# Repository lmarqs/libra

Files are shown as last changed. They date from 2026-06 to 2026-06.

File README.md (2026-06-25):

# Libra

<p align="center">
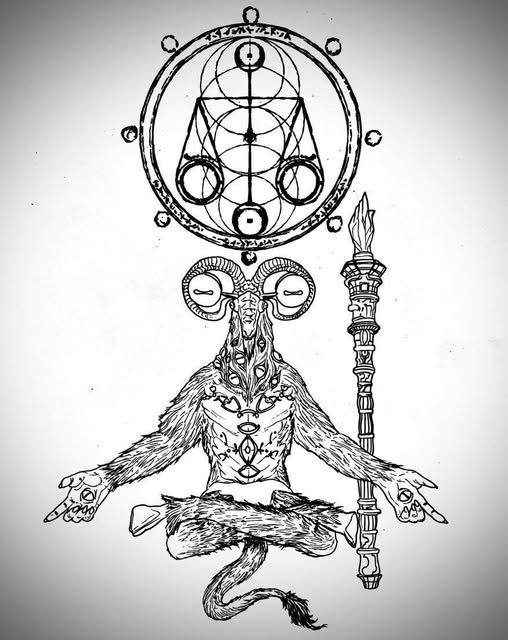
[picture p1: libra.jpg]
Libra emblem — a balanced, cross-legged figure beneath a scale-like sigil
  
</p>

A self-balancing **beam** for hands-on PID experimentation.

A weighing-scale–style beam pivots at its center, with a brushless motor +
propeller at each end. Differential propeller thrust rotates the beam; an
MPU6050 measures the beam's tilt; a PID loop running on an **ESP32** (C3 Super
Mini or WROOM-32) drives the two ESCs to hold a target angle (level by default). It's a
single rotational axis — the simplest interesting plant for learning to tune P,
I, and D. Tuning and telemetry are over the USB serial console, or over an optional
WiFi web UI (target tilt, PID gains, arm/disarm). It boots disarmed; the ESC power
supply also has a separate hardware switch.

## Hardware

| Part | Notes |
|---|---|
| ESP32-C3 Super Mini *or* ESP32 WROOM-32 | Controller. C3 = single-core RISC-V + native USB; WROOM-32 = dual-core + USB-UART bridge. |
| MPU6050 | 6-axis IMU, I2C. Mounted on the beam to read tilt. |
| 2× brushless motor + ESC | 1000–2000 µs ESCs, driven at 200 Hz / sub-µs via LEDC. Arming is a hardware power switch. |
| 2× propeller | One per beam end, providing the balancing thrust. |
| LiPo battery | Powers the motors through the ESCs (behind the hardware arm switch). |

Pins are board-specific — literal `-D` flags per `[env]` in `platformio.ini`
(`src/config.h` defaults apply when unset). Verify against your board's silkscreen.
**C3 Super Mini:** I2C `SDA=GPIO2`, `SCL=GPIO3`; ESCs on `GPIO0`/`GPIO1` (`GPIO2` is
a strapping pin but fine for SDA — I2C idles high; keep `GPIO8`/`GPIO9` and USB
`GPIO18`/`GPIO19` free). **WROOM-32:** I2C `SDA=GPIO32`, `SCL=GPIO33`; ESCs on
`GPIO16` (left/m1) / `GPIO17` (right/m2) — non-strapping and free on the plain
WROOM-32 (the WROVER variant reuses 16/17 for PSRAM); avoid the classic-ESP32
strapping pins `GPIO0`/`GPIO2`/`GPIO12`/`GPIO15`.

**Reference build** (what this is validated on): 1404 4600 KV motors, Afro Mini
ESCs (SimonK/BLHeli), Gemfan 3523-3 props, 3S LiPo, and a hardware switch on the
ESC power as the arm. Any standard 1000–2000 µs ESC + small brushless motor works —
expect to re-find the usable throttle band for your motor (see
[docs/testing.md](docs/testing.md) → Bench testing & ESC calibration).

### Printed frame

The mechanical rig is 3D-printed — sources and print files live in
[`docs/3dprint/`](docs/3dprint/). The base and tower raise the pivot; the arm
pivots on the tower with a motor plate bolted to each end:

| Part | Role |
|---|---|
| [`base`](docs/3dprint/base.png) | Wide honeycombed foot that sits on the desk; the square center socket holds the tower. |
| [`tower`](docs/3dprint/tower.png) | Vertical post that plugs into the base and raises the pivot off the bench. |
| [`arm`](docs/3dprint/arm.png) | The balancing beam: a central pivot hub (rides on the tower) with a motor plate at each end. |
| [`plate`](docs/3dprint/plate.png) | Motor mount — one bolts to each end of the arm and carries a brushless motor (the 4-hole bolt pattern). |

Each part ships in four formats: `.f3d` (Fusion 360 source — edit here), `.stl` and
`.3mf` (print-ready mesh for your slicer), and `.png` (a render preview).

### Flashing

The C3 Super Mini has native USB — just plug it in and run `mise run upload`. If
the upload can't connect, enter download mode once: hold **BOOT**, tap **RST**,
release BOOT, then upload (the USB-CDC auto-reset handles it after that).

> ⚠️ **Props spin.** Bench-test with propellers removed or the beam clamped.
> Boots **disarmed** — arm from the web UI when ready, and the ESC supply also has a
> separate **hardware switch** (keep it OFF until you trust your gains). The tilt
> failsafe cuts the motors and latches disarmed.

## Architecture

A dedicated, core-pinned control task reads the IMU, runs the control policy, and
drives the ESCs, sleeping to its period (`xTaskDelayUntil`) between steps and polling
the USB serial console non-blockingly so it never stalls. It's pinned to the APP core
(core 1 on the dual-core WROOM-32 — isolated from the WiFi stack on core 0; the only
core on the C3) at a priority above the web server but below WiFi, so control stays
responsive while WiFi is never starved. The optional web UI runs as an HTTP server
(ESP-IDF `httpd`) in its own task; it exchanges the setpoint, gains, telemetry, and
arm/disarm (the software master-enable) with the control task — the ESC supply is a
separate hardware switch. `dt` is measured each step, so it tolerates timing jitter.

```mermaid
flowchart LR
    mpu["MPU6050 IMU"] -->|I2C| loop
    subgraph c3["ESP32 (C3 single-core / WROOM-32 dual-core)"]
        direction TB
        loop["control loop @200 Hz<br/>Imu → Balancer.step() → EscPair"]
        serial["USB serial console<br/>tuning + telemetry"]
        web["httpd :80 (own task)<br/>/ · /telemetry · /set"]
        serial <-->|"kp/ki/kd · sp · ?"| loop
        web <-->|"sp · kp/ki/kd · arm · telemetry"| loop
    end
    loop -->|"1000–2000 µs PWM"| esc["2× ESC → motor → prop"]
    browser["Browser<br/>arm + tilt + gain sliders"] <-->|"WiFi AP · HTTP"| web
```

The control policy lives in `Balancer.step()` (`lib/balancer/`): fuse the tilt
estimate, trip the failsafe past the limit, otherwise run PID into the mixer.
While disarmed or tripped the motors idle; the integrator resets on each (re-)arm so
stale wind-up can't kick.

```mermaid
flowchart LR
    accel["accel angle"] --> filt["ComplementaryFilter"]
    rate["gyro rate"] --> filt
    filt -->|"fused tilt"| trip{"abs(angle) ><br/>tilt limit?"}
    trip -->|yes| idle["idle motors<br/>+ trip failsafe"]
    trip -->|"no"| pid["Pid<br/>(anti-windup)"]
    sp["setpoint"] --> pid
    pid -->|correction| mix["Mixer<br/>(base ± correction)"]
    mix --> out["m1, m2 → ESCs"]
```

**Host/hardware split.** `lib/{filter,pid,mixer,balancer}` are pure C++ with no
Arduino deps, so the whole control policy is unit-tested on the host
(`mise run test`). `Imu` and `EscPair` are Arduino-only hardware drivers.

## PID control

Balancing the beam is the whole point — a single rotational axis is the simplest
interesting plant for learning to tune a **PID** controller by hand. Each step the
loop measures the tilt, computes one corrective number, and turns it into
differential propeller thrust; the beam moves, the IMU re-measures, and the cycle
repeats 200×/s (`Balancer::step` → `Pid::update` → `Mixer::mix`).

```mermaid
flowchart LR
    sp["setpoint<br/>(target tilt)"] --> e{{"error<br/>= setpoint − angle"}}
    imu["measured tilt<br/>(fused IMU angle)"] --> e
    e --> p["P = Kp · error<br/>correct now"]
    e --> i["I = Ki · Σ(error·dt)<br/>cancel a steady lean"]
    imu --> d["D = −Kd · Δangle/dt<br/>damp the swing"]
    p --> sum(("Σ"))
    i --> sum
    d --> sum
    sum -->|"correction (clamped ±kPidOutLimit)"| mix["Mixer<br/>m1 = base + correction<br/>m2 = base − correction"]
    mix -->|differential thrust| beam["beam rotates"]
    beam -.->|IMU re-measures| imu
```

The controller sums three responses to the **error** (how far the tilt is from the
target). The mixer turns that single correction into two throttles around a common
`base` — one motor speeds up while the other slows down — which is what rotates the
beam.

| Term | Gain (cmd) | What it contributes | Default |
|---|---|---|---|
| **P** — proportional | `kp` | A restoring push proportional to the current error (throttle fraction per degree of tilt) — the main spring. *Too high → oscillation.* | `0.002` |
| **I** — integral | `ki` | Sums past error to cancel a constant offset P alone can't hold (e.g. an off-center load). *Too high → slow overshoot / hunting.* | `0.000` (off) |
| **D** — derivative | `kd` | Reacts to how fast the tilt is changing and brakes it before it overshoots. Taken on the *measurement*, not the error, so moving the setpoint doesn't kick the motors. *Too high → jitter on sensor noise.* | `0.0008` |

Bounds keep it safe: each motor command is clamped to the throttle band
`[kMinThrottle, kMaxThrottle]` around the hover point `kBaseThrottle` (the PID's authority is
sized so a full correction can drive one motor to `kMaxThrottle` while the other drops to
`kMinThrottle`), and past `kTiltLimitDeg` the tilt failsafe cuts both motors and latches
disarmed (see the ⚠️ safety notes above).

### Tuning

Tune **live** — set gains with `kp`/`ki`/`kd <v>` and nudge the target with
`sp <deg>`, over serial or the web sliders (command reference in *Tuning over
serial* below). Keep **props off or the beam clamped** until the gains are sane.

1. Start with `ki 0` and `kd 0`; raise `kp` until the beam fights back toward level
   but slightly oscillates.
2. Add `kd` to damp that oscillation — increase until the swing settles cleanly
   without buzzing on noise.
3. Add a little `ki` *only* if the beam holds a constant offset from level; back it
   off if it starts a slow hunting overshoot.

Watch the response with `mise run probe` (one `?` state line: `angle`, `out`,
`m1`/`m2`, gains) or `mise run stream` (continuous).

### Testing

`lib/pid` (with `filter`/`mixer`/`balancer`) is pure, host-tested math — run the
unit cases with no hardware, then tune the gains on the rig:

```sh
mise run test     # Unity cases for pid / filter / mixer / balancer
```

## Toolchain

Everything runs through [mise](https://mise.jdx.dev/), which loads `.env` and
manages the Python venv holding PlatformIO. **Always use the mise tasks** so the
environment is set up correctly.

```sh
mise run setup     # one-time: create .env + venv, install PlatformIO
mise run build     # compile the default env (esp32-wroom32)
mise run upload    # build + flash over USB
mise run monitor   # open the serial monitor (115200 baud)
mise run run       # build + upload + monitor
mise run test      # host-side unit tests (pid / filter / mixer / balancer)
mise run format    # clang-format src/ lib/ test/
mise run probe     # ask the board its state over serial ('?')
mise run banner    # reset + capture the boot banner
mise run stream    # capture serial output (e.g. the debug IMU stream)
```

**Testing & debugging** — host tests, flashing, talking to the board, the debug
log level, and IMU bring-up are covered in **[docs/testing.md](docs/testing.md)**.

## Configuration

Deployment tunables come from **`.env`** (gitignored — `mise run setup` copies
`.env.example`); mise loads `.env` and PlatformIO injects each as a `-D` build flag,
with `src/config.h` defaults applying when unset. The board **pin map** is separate:
literal `-D` flags per `[env]` in `platformio.ini`, not `.env`. **Edit `.env` (or the
env's pins), then rebuild** (`mise run build` / `upload`) to apply.

| Variable | Default | Purpose |
|---|---|---|
| `LIBRA_THROTTLE_MIN` | `0.0` | Hard floor of the per-motor throttle band (0..1 fraction of the ESC's 1000–2000 µs range) — a motor never goes below it. |
| `LIBRA_THROTTLE_MID` | `0.0` | Hover point — where both motors rest at zero error. Set independently within `[MIN, MAX]`. |
| `LIBRA_THROTTLE_MAX` | `0.0` | Hard ceiling — a motor never goes beyond it. PID authority is derived to reach the farther edge from `MID`, so the motors sweep `[MIN, MAX]`. Ships as a zero band (inert) — set all three to your motor before balancing does anything. |
| `LIBRA_TILT_LIMIT_DEG` | `45.0` | Tilt failsafe — past this many degrees the motors cut and latch disabled. |
| `LIBRA_ANGLE_OFFSET_DEG` | `0.0` | Tilt zero-offset (deg), subtracted so a physically level beam reads 0. |
| `LIBRA_AP_SSID` | `libra` | WiFi SoftAP name for the web UI. |
| `LIBRA_AP_PASS` | `thebalancebot` | WPA2 password for that AP (web UI can arm, so it's secured by default — a public default, override it in `.env`). Empty or `< 8` chars → open AP. |

(Pin map is not here — it's board-specific `-D` flags in `platformio.ini`; see [Hardware](#hardware).)

**Convention:** name new **tunables** `LIBRA_<AREA>_<NAME>`, document them in
`.env.example` with their default, and back each with an `#ifndef` default in
`src/config.h`. Board pins are literal `-D` flags in `platformio.ini` per `[env]`,
not `.env` knobs (see [CLAUDE.md](CLAUDE.md) for the full pattern).

## Tuning over serial

Open the serial monitor (`mise run monitor`, 115200 baud) and type commands:

| Command | Effect |
|---|---|
| `kp <v>` / `ki <v>` / `kd <v>` | set a PID gain live |
| `sp <v>` | set the target tilt, degrees |
| `?` | print state (angle, output, motor throttles, gains) |

There is no *serial* arm/disarm — **arm/disarm is from the web UI** (the software
master-enable; boots disarmed), and the **ESC supply has a separate hardware switch**.
Exceeding the tilt limit cuts the motors and latches disarmed (re-arm from the web).
The setpoint and gains (`sp`, `kp`, `ki`, `kd`) are also settable from the web UI below.

## Web control

On boot the board starts a WiFi access point and a small web UI for live tuning:

1. Join the WiFi network named by `LIBRA_AP_SSID` (default `libra`). It ships
   **WPA2-secured** with the default password `thebalancebot` (`LIBRA_AP_PASS`);
   change it in `.env`, or set it empty for an open AP.
2. Browse to **`http://192.168.4.1/`**.
3. **ARM** / **DISARM** with the buttons, and use the sliders for target tilt + PID
   gains. The page shows the live angle and the armed/tripped state.

The web UI sets the setpoint, gains, and **arm/disarm** (the software master-enable);
it cannot change a limit, and a web-set target is clamped to the tilt limit. The board
boots **disarmed**, and the ESC power is behind a separate hardware switch — but since
the web can arm, the AP is **WPA2-secured by default** (`LIBRA_AP_PASS=thebalancebot`).
That default is public, so **change `LIBRA_AP_PASS`** when props are on or anyone could be
in range — and never set it empty (open AP, any client can arm) in an untrusted RF area.

## Status

Built incrementally:

- **M0** — toolchain + docs: builds, flashes, prints a boot banner.
- **M1** — IMU angle readout (complementary filter).
- **M2** — ESC bring-up + arming.
- **M3** — closed PID loop with tilt failsafe + serial tuning.
- **M4** — WiFi web UI: live tuning + two-layer arming (boots disarmed; ESC power on a separate hardware switch).
- **M5** — props-off bench tooling: per-motor manual drive + ESC throttle-range calibration & sweep.

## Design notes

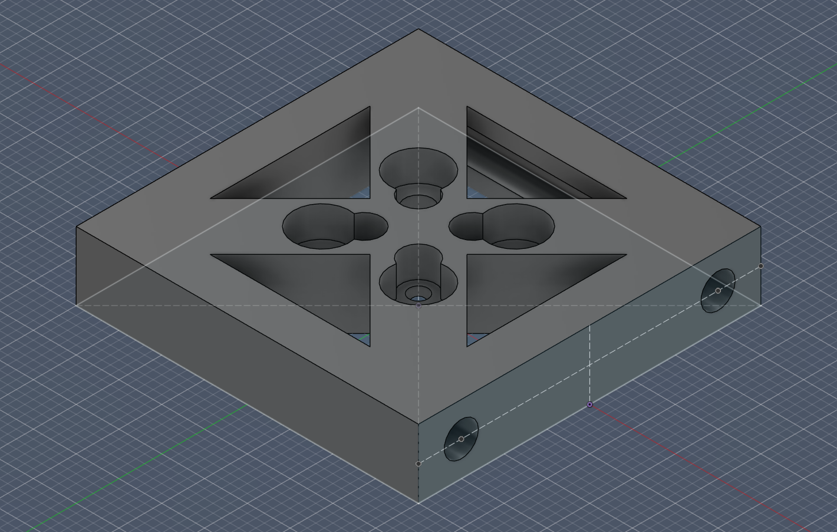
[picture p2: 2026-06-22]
docs/3dprint/plate.png

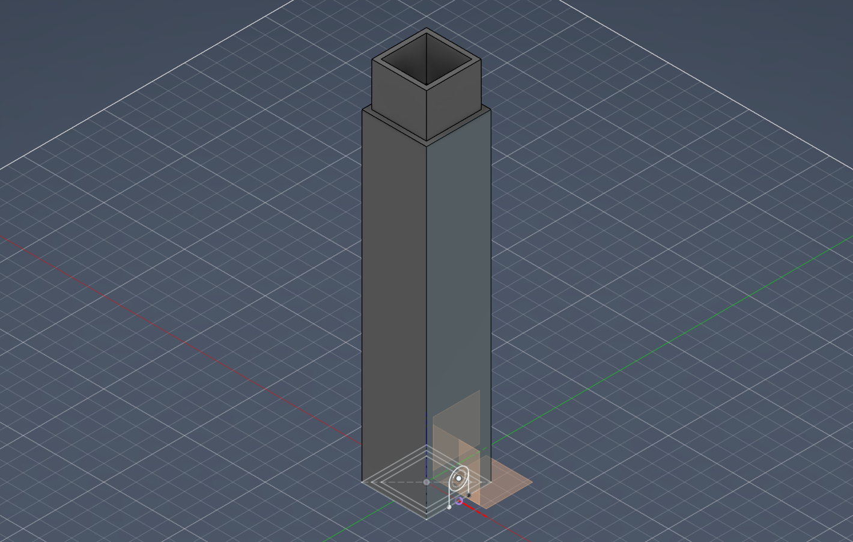
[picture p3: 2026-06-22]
docs/3dprint/tower.png

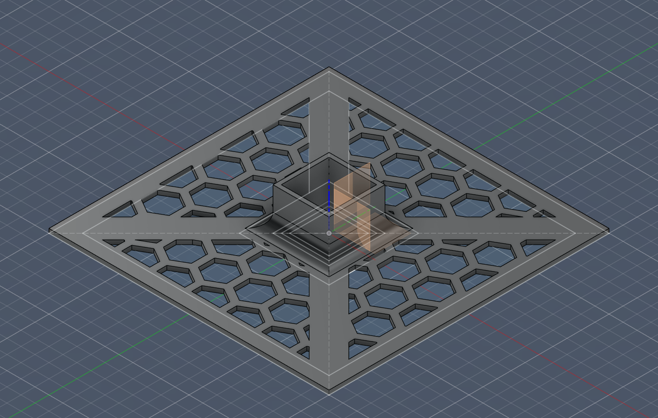
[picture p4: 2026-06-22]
docs/3dprint/base.png

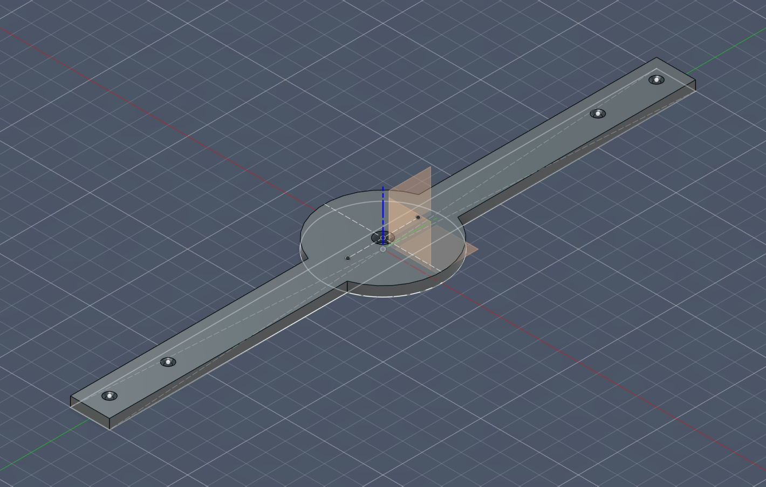
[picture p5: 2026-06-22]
docs/3dprint/arm.png

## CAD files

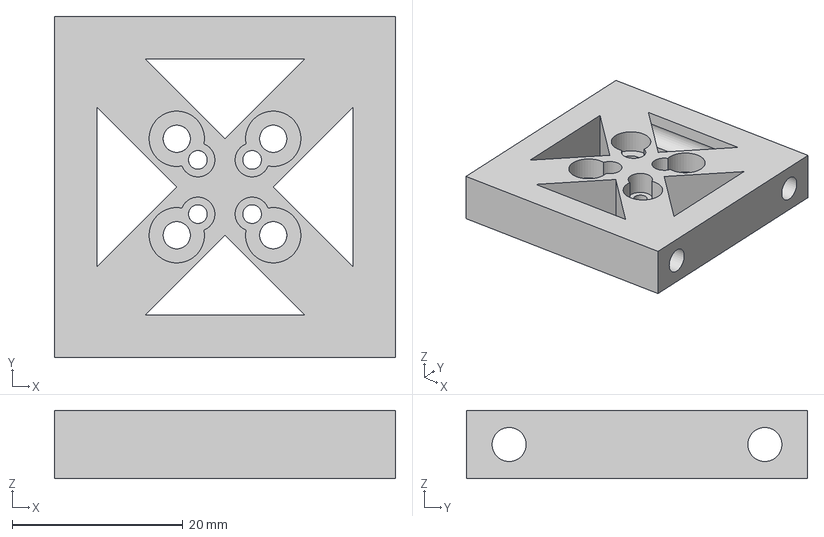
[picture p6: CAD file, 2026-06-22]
docs/3dprint/plate.3mf
40.0 x 40.0 x 8.00 mm

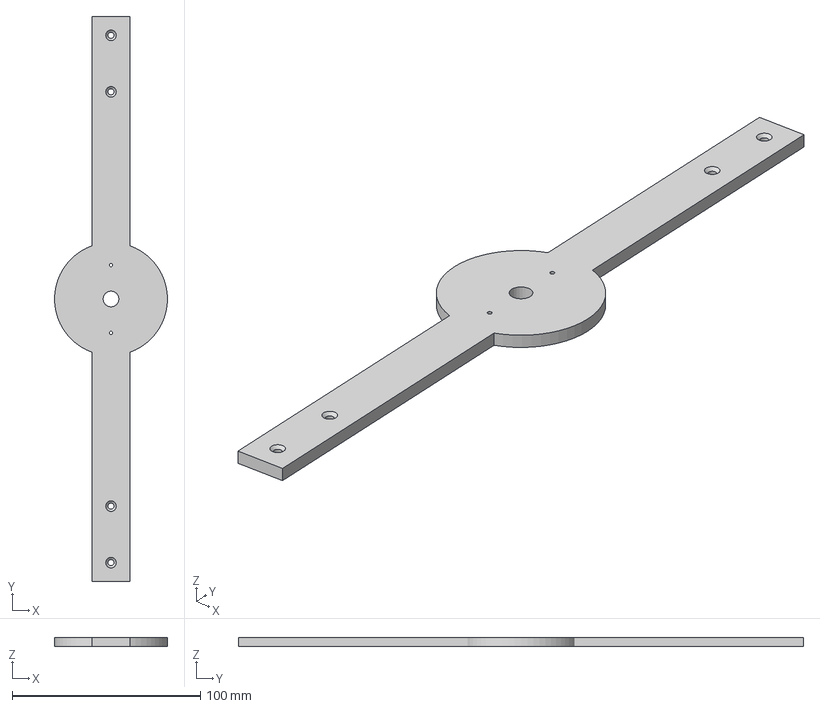
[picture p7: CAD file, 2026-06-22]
docs/3dprint/arm.3mf
60.0 x 300.0 x 5.00 mm

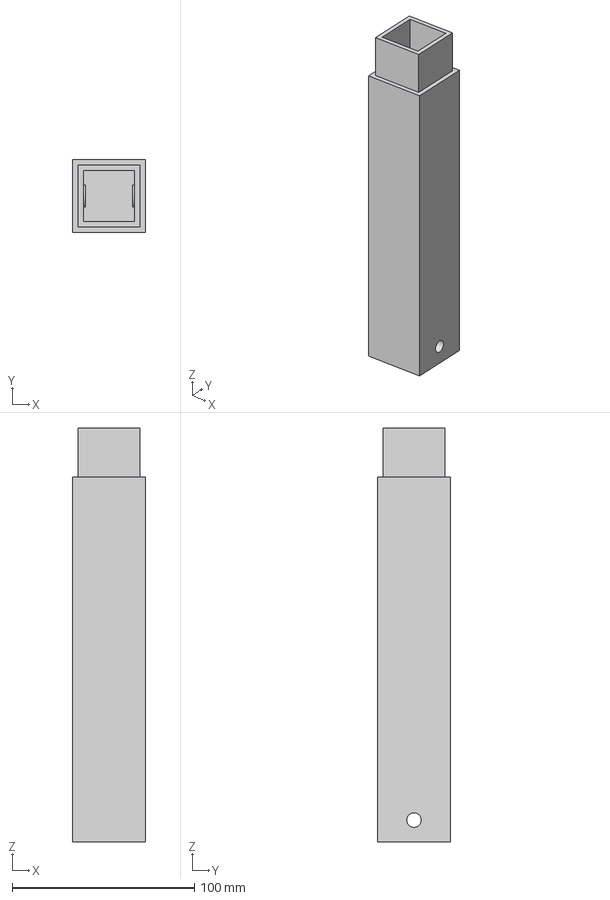
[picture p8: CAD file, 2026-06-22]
docs/3dprint/tower.3mf
40.0 x 40.0 x 227.0 mm

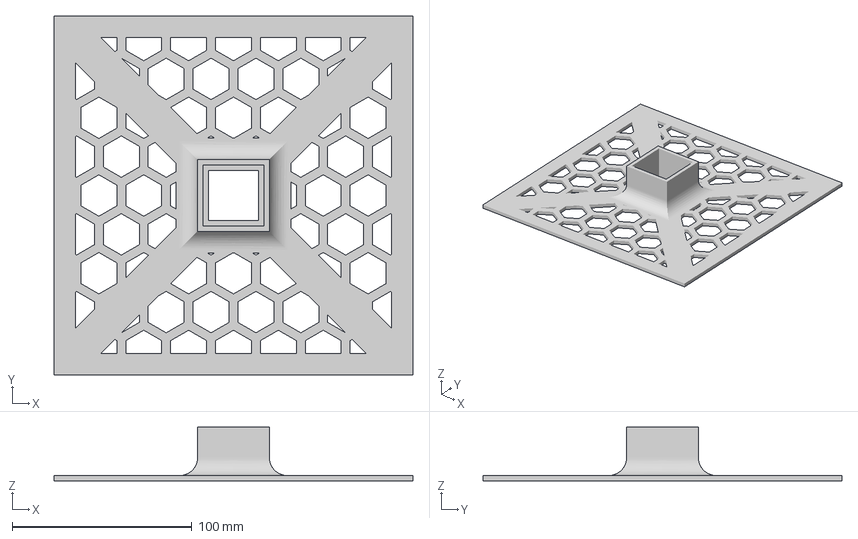
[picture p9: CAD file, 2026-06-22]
docs/3dprint/base.3mf
200.0 x 200.0 x 30.0 mm

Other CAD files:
docs/3dprint/arm.f3d
docs/3dprint/arm.stl
docs/3dprint/base.f3d
docs/3dprint/base.stl
docs/3dprint/plate.f3d
docs/3dprint/plate.stl
docs/3dprint/tower.f3d
docs/3dprint/tower.stl

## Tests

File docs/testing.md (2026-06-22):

# Testing & debugging

How to test and debug Libra effectively — host tests, build/flash, talking to the
board, debug logging, and sensor bring-up. The fast loop is host unit tests; the
board is reached over serial, non-interactively.

## TL;DR — the loop

```sh
mise run test          # host unit tests (pure libs) — fast, no hardware
mise run build         # compile the default env (esp32-wroom32)
mise run build:all     # compile BOTH boards — the dual-arch gate
mise run upload        # flash over USB
mise run probe         # ask the board its state ('?') and print the reply
mise run banner        # reset + capture the boot banner
mise run stream        # capture serial for 30s (e.g. the debug IMU stream)
mise run format-check  # clang-format clean
```

Gate before declaring a change done: **`mise run test` + `mise run format-check` + `mise run build:all`**.

## 1. Host unit tests — the primary correctness loop

The pure control libs (`lib/{pid,filter,mixer,balancer}`) have **no Arduino deps**
and are unit-tested on the host via the PlatformIO `native` env:

```sh
mise run test          # Unity tests; currently 21 cases
```

This needs no board and runs in seconds — do most logic work here. **Add or extend
Unity tests in `test/` whenever you touch a pure lib.** Hardware drivers (`imu`,
`esc`, `web`) are deliberately *not* host-compiled, so keep Arduino/`Wire`/WiFi
includes out of the pure libs (the `native` env would fail to build them).

## 2. Build & flash

Two boards build from one tree (per-board pin map + flags live in `platformio.ini`):
the **ESP32-C3 Super Mini** (single-core, native USB) and the **ESP32 WROOM-32**
(dual-core, USB-UART bridge). `mise run build` compiles the default env
(`esp32-wroom32`); target a specific board by passing the env through mise:

```sh
mise run build                            # default env (esp32-wroom32)
mise run build:all                        # both boards — dual-arch compile gate
mise x -- pio run -e esp32-c3-super-mini  # just the C3
mise run upload                           # build + flash (default env)
mise run run                              # build + upload + monitor, in order
```

If `upload` can't connect on the C3, enter download mode once: hold **BOOT**, tap
**RST**, release BOOT, then upload. USB-CDC auto-reset handles it afterwards.

### Concurrency / core model (both archs)

The control loop runs in a dedicated `controlTask` pinned to `ARDUINO_RUNNING_CORE`:
the **APP core (1)** on the dual-core WROOM-32 (isolated from WiFi/`httpd` on the PRO
core 0), and the **only core (0)** on the single-core C3 (where its priority `10` —
above `httpd`, below lwIP/WiFi — plus the per-period `xTaskDelayUntil` yield keep WiFi
alive). A `LIBRA_LOG_LEVEL>=4` build logs the task's core and stack high-water-mark, so
you can confirm `core=1` on the WROOM / `core=0` on the C3 and that the 8 KB stack has
headroom. See CLAUDE.md → Gotchas for the full rationale and the watchdog invariant.

## 3. Talking to the board over serial

### Why the monitor looks dead

The firmware prints a boot banner **once** and then only replies to commands — it
does not stream by default. And the C3's native USB-CDC does **not** reset the chip
when a monitor attaches (unlike a UART bridge), so the banner has already scrolled
past. Result: `mise run monitor` shows a blank screen until you type. That's
expected, not a fault. Type `?` for a state line, or press **RST** to re-emit the
banner.

### Non-interactive helpers (preferred)

`tools/serial_dbg.py` (wrapped by mise) talks to the board without a live terminal —
scriptable, CI/agent-friendly, and it resets the board cleanly (pulses EN via RTS
into the **app**, not the bootloader):

```sh
mise run probe                                           # send '?', print the state line
mise x -- python tools/serial_dbg.py probe --cmd "kp 0.02"   # send any command
mise run banner                                          # reset + capture the boot banner
mise run stream                                          # capture 30s of serial
mise x -- python tools/serial_dbg.py stream --seconds 20 --grep "gx="  # filter lines
```

A typical `probe` reply (all serial output now goes through the ESP32 `log_*` API, so each
line carries a `[time][level][file:line] func():` prefix — the `state:` fields follow it):

```
[ 12345][I][main.cpp:127] handleCommand(): state: angle=-0.24 sp=0.00 out=0.000 m1=0.00 m2=0.00 kp=0.0100 ki=0.0000 kd=0.0008
```

The state line is `log_i`, so `probe`/`banner` need `LIBRA_LOG_LEVEL >= 3` (the default) to
see it; below 3 only errors/warnings print.

### Serial command reference

| Command | Effect |
|---|---|
| `kp <v>` / `ki <v>` / `kd <v>` | set a PID gain live |
| `sp <v>` | set the target tilt, degrees |
| `?` | print state (angle, output, throttles, gains; or bench throttle) |
| `set motors_enabled on\|off` | bench: drive the motors at the set speeds, or hold both idle — props off |
| `set motors_speed <m1> <m2>` | bench: per-motor throttle, each 0..1 (full range, for calibration) |
| `run` | leave bench and resume balancing |
| `x` | stop: hold motors idle (the hardware ESC switch is the real kill) |

The four bench rows (`set motors_*`, `run`, `x`) exist only in a **`LIBRA_BENCH_ENABLED=1`**
build (§7); otherwise just `kp/ki/kd/sp/?`. Setpoint, gains, **and arm/disarm** are settable from
the WiFi web UI (the software master-enable; boots disarmed) — the ESC supply is a separate
hardware switch (see §7).

## 4. Debug logging — env-var log level

**All** serial output goes through the ESP32 `log_*` API (`CORE_DEBUG_LEVEL`), driven by
`LIBRA_LOG_LEVEL` in `.env` (0=none, 1=error, 2=warn, 3=info, 4=debug, 5=verbose). So the
level gates everything, not just the IMU stream — each line is prefixed
`[time][level][file:line] func():`:

- **≥ 1 (error)** failures: `MPU6050 not found`, `WiFi SoftAP failed`, `HTTP server failed`.
- **≥ 2 (warn)** invalid-command help.
- **≥ 3 (info)** the boot banner, `state:` replies, and AP join/leave events. This is why
  `probe`/`banner` need level ≥ 3 (the default). Bench/calibration prompts are `log_w` (≥ 2).
- **≥ 4 (debug)** compiles in a ~10 Hz raw-IMU stream via `log_d()` — the bring-up tool.
  Below 4 it is compiled out entirely (zero runtime cost).
- `Serial.setDebugOutput(true)` routes `log_*()` to the USB-CDC — load-bearing for *all*
  output now, not just debug.
- Default is **3**; bump to 4, rebuild, and watch with `mise run stream` only while
  bringing up the IMU.

```sh
# enable the IMU stream
sed -i 's/^LIBRA_LOG_LEVEL=.*/LIBRA_LOG_LEVEL=4/' .env && mise run upload
mise run stream                       # lines look like: ... step(): ax=.. gx=.. acc=.. fused=..
```

Each line carries the raw accel (`ax/ay/az`, g), gyro (`gx/gy/gz`, °/s), the
accel-derived angle (`acc`), and the filtered angle (`fused`).

## 5. Sensor bring-up — IMU axis & zero-offset

The IMU mapping is mounting-specific. To (re-)derive it after a remount:

1. Build with `LIBRA_LOG_LEVEL=4`, flash, and `mise run stream`.
2. Move the beam: **hold level → rotate CW and hold → level → rotate CCW → level**,
   pausing between phases.
3. Read off the trace:
   - **Accel angle axis** — at level, see which accel axis carries ~+1 g. Gravity
     resting on +X with tilt swinging into Y means the angle is `atan2(ay, ax)`
     (set in `Imu::accelAngleDeg`).
   - **Pivot gyro axis + sign** — the gyro axis that spikes during rotation is the
     rate. Use it negated/un-negated so the **fused** angle tracks **acc** during
     motion (here `-s.gz`, in `main.cpp`). If fused lags or diverges from acc, flip
     the sign.
   - **Zero-offset** — read the steady angle at physical level and put it in
     `LIBRA_ANGLE_OFFSET_DEG` (`.env`) so level reads 0.

This rig's result: `atan2(ay, ax)`, rate `-s.gz`, offset `-3.4°`.

## 6. WSL2 serial notes

- Device: **`/dev/ttyACM0`** — the C3's built-in USB-Serial/JTAG (VID:PID
  `303A:1001`), shared into WSL via `usbipd-win`.
- **Port busy** (`Could not exclusively lock port … Resource temporarily
  unavailable`): a monitor holds it. Close `mise run monitor`/`run`, or find the
  holder: `lsof /dev/ttyACM0`, `fuser -v /dev/ttyACM0`, or scan
  `/proc/*/fd` for the symlink to `ttyACM0`.
- A reset re-enumerates USB; `usbipd` can detach the device — re-attach from
  Windows (`usbipd attach --wsl --busid <id>`) if `/dev/ttyACM0` disappears.

## 7. Bench testing & ESC calibration (props off)

**Arming is two-layer.** The board boots **disarmed**; you arm/disarm the software master-enable
from the web UI, and the **ESC power supply has a separate hardware switch** (keep it OFF until
ready). The tilt failsafe cuts the motors and latches disarmed around `LIBRA_TILT_LIMIT_DEG`.
Always bench-test with **props off or the beam clamped**.

The bench commands are **compiled out by default** — build with `LIBRA_BENCH_ENABLED=1` in
`.env` to use them, and set it back to `0` for a props-on build. They drive the ESCs directly
and **bypass both the `kMaxThrottle` cap and the tilt failsafe** (you raise throttle yourself;
nothing auto-jumps), which is why they are gated and props-off only. The serial commands are
`set motors_enabled on|off`, `set motors_speed <m1> <m2>` (each 0..1), `run` (resume balancing),
`x` (idle) — see §3.

### Find the usable band — `mise run sweep`

`tools/sweep.py` ramps the throttle and holds each step so you can watch the motor and read the
pulse it sends. It reports throttle as a *fraction* of the firmware's real **200 Hz /
1000–2000 µs** signal (driven sub-µs off LEDC, ~0.3 µs steps) — not the duty cycle of a bench
PWM generator, which the ESC reads differently (4 kHz @ 39/79% ≈ 98/198 µs, far below the 1–2 ms
the ESC expects).

```sh
mise run sweep                                                # 0.00->0.10, both motors
mise x -- python tools/sweep.py 0.07 0.10 0.001 2             # narrow + fine, 2 s holds
mise x -- python tools/sweep.py 0.07 0.10 0.001 2 --motor seq # test each motor in turn
mise x -- python tools/sweep.py --port /dev/ttyACM0          # C3 port
```

`--motor 1|2|seq` drives one motor at a time — handy when only one spins (an armed ESC that
ignores throttle on one channel points at *that* ESC's power/arming or a wiring/pin issue, not
the firmware). Note the **spin-start** (lowest throttle that turns the prop) and a usable top
speed. *(Reference build — 1404 4600 KV on 3S, Gemfan 3523-3, Afro Mini — spins from ~1080 µs
and is plenty by ~1090 µs.)*

### Set the operating band

The balancer drives both motors within a throttle band set in `.env` by three knobs — 0..1
fractions of the ESC's 1000–2000 µs range:

- `LIBRA_THROTTLE_MIN` — hard floor; a motor never goes below it (keep it at or above the
  spin-start so both motors stay turning).
- `LIBRA_THROTTLE_MID` — the hover point; where both motors rest at zero error.
- `LIBRA_THROTTLE_MAX` — hard ceiling; a motor never goes beyond it.

`kBaseThrottle` is `MID`; `kPidOutLimit` in `config.h` is *derived* as the max headroom
(`max(MAX − MID, MID − MIN)`), so a full correction can drive a motor to the farther edge and the
mixer clamp holds the nearer one — a motor sweeps the whole `[MIN, MAX]`. The committed default is
a **zero band `[0.0, 0.0]`** with hover 0, so a fresh build is inert until you set a real band.
Widening the band raises both thrust and control authority — a change the safety rules guard (see
[CLAUDE.md](../CLAUDE.md)).

### Optional: ESC throttle-range calibration (SimonK / BLHeli)

Only needed if the ESC's learned range is off (the motor refuses to spin until very high
throttle). The ESC must see **MAX at power-up**, and `escs.begin()` holds MIN for ~3 s at boot,
so the ESC must be on a **switch separate from the board** — you present MAX yourself:

1. ESC switch **OFF**; boot the board (it emits its arm signal at MIN, then idles).
2. `set motors_speed 1 1` then `set motors_enabled on` — firmware now streams MAX.
3. Switch the ESC **ON**: it powers up seeing MAX and beeps to record the top.
4. `set motors_speed 0 0` — drops to MIN; the ESC beeps to store the range.
5. `run`, then switch the ESC **OFF**. Re-sweep to confirm the spin-start dropped near idle.

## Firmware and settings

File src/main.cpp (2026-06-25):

// Libra — self-balancing beam (ESP32-C3 single-core and ESP32 WROOM-32 dual-core).
//
// A dedicated fixed-rate control task reads the IMU, runs the control policy
// (complementary filter -> PID -> mixer), and drives the two ESCs — gated by a software
// master-enable (armed from the web UI; boots DISARMED) and the tilt failsafe. The ESC
// supply is gated by a separate HARDWARE switch. Tuning + telemetry are over USB serial
// and the WiFi web UI (setpoint, gains, arm/disarm).
//
// Concurrency model (see CLAUDE.md): the control task is pinned to
// ARDUINO_RUNNING_CORE — the APP core (1) on the dual-core WROOM, isolated from the
// WiFi/lwIP/httpd stack on the PRO core (0); the only core on the single-core C3,
// where priority + a per-period yield keep WiFi alive instead.
//
//   ⚠️  Boots DISARMED. Arm/disarm from the web UI (the software master-enable); the ESC
//       supply is a separate HARDWARE switch — keep it OFF until ready. Past the tilt limit
//       the failsafe cuts the motors and latches DISARMED — re-arm from the web. Props off
//       / beam clamped while you trust your gains.
//
// Serial commands (USB-CDC, 115200): kp <v> | ki <v> | kd <v> | sp <v> | ?
//   Bench / ESC calibration (PROPS OFF): set motors_enabled on|off | set motors_speed <m1> <m2> | run | x
//   (motors default to 0 and only move when enabled; raise to 1.0 then 0.0 by hand to calibrate.)
//
// Build with LIBRA_LOG_LEVEL>=4 (.env -> CORE_DEBUG_LEVEL) to stream raw IMU
// readings over serial via log_d() — used for IMU axis/bias bring-up.

#include <Arduino.h>
#include <Balancer.h>
#include <EscPair.h>
#include <Imu.h>
#include <Throttle.h>
#include <Wire.h>

#include "config.h"
#include "web.h"

static Imu imu(config::kMpuAddress);
static EscPair escs(config::kEsc1Pin, config::kEsc2Pin);
static Balancer balancer(ComplementaryFilter(config::kFilterAlpha),
                         Pid({config::kKp, config::kKi, config::kKd}, -config::kPidOutLimit, config::kPidOutLimit),
                         Mixer(config::kBaseThrottle, config::kMinThrottle, config::kMaxThrottle),
                         config::kTiltLimitDeg);

// Operator + control state — single execution context (controlTask), so plain variables.
static Pid::Gains gains{config::kKp, config::kKi, config::kKd};
static float setpoint = config::kSetpointDeg;
static bool enabled = false;  // software master-enable; boots DISARMED, armed from the web UI
static ControlOutputs last{};

// Bench / manual-drive override (controlTask-owned), compiled in only with LIBRA_BENCH_ENABLED.
// While `benchActive`, the control loop skips balancing and the operator drives each ESC
// directly: `motorsOn` gates whether the per-motor speeds are applied or both held at idle
// (min). Speeds default to 0, so nothing ever jumps to throttle on its own — for ESC
// calibration you raise them to 1.0 yourself. Props-off bench only; it bypasses the
// kMaxThrottle cap and the tilt failsafe, which is why it is gated off by default.
#if LIBRA_BENCH_ENABLED
static bool benchActive = false;              // manual mode engaged (balancing suspended)
static bool motorsOn = false;                 // drive the speeds, vs. hold both at idle
static float m1Speed = 0.0f, m2Speed = 0.0f;  // per-motor bench throttle, 0..1
#endif

// --- Control task placement (timers/tasks/loops; dual-arch) ---
#ifndef ARDUINO_RUNNING_CORE
#define ARDUINO_RUNNING_CORE 0  // defensive; the framework defines it (1 on dual, 0 on C3)
#endif
// Run control on ARDUINO_RUNNING_CORE: the APP core (1) on the dual-core WROOM —
// physically isolated from WiFi/lwIP/httpd on the PRO core (0) — and the only core on
// the single-core C3, where the priority below + the per-period yield keep WiFi alive.
static constexpr BaseType_t kControlCore = ARDUINO_RUNNING_CORE;
// Above httpd (tskIDLE_PRIORITY+5 = 5) so control preempts the web server on the C3;
// below lwIP (18) / WiFi (23) so the WiFi stack is never starved. MUST stay < 18.
static constexpr UBaseType_t kControlPrio = 10;
// Matches the Arduino loopTask budget; the step path uses String/snprintf/atan2f.
static constexpr uint32_t kControlStackBytes = 8192;

static void step(float dt) {
#if LIBRA_BENCH_ENABLED
  // Bench override: drive each ESC at its manual speed (or hold idle) and skip balancing.
  // Still publish (with bench=true) so the web UI never shows a safe-looking state while
  // the motors are live.
  if (benchActive) {
    escs.writeThrottle(motorsOn ? m1Speed : 0.0f, motorsOn ? m2Speed : 0.0f);
    web::publish(last.angle, enabled, /*tripped=*/false, /*bench=*/true, gains, setpoint);
    return;
  }
#endif

  web::poll(gains, setpoint);  // apply any web-set gains/setpoint before computing
  const int arm = web::pollArm();
  if (arm >= 0) enabled = (arm == 1);  // web arm/disarm; control loop owns `enabled`

  ImuSample s;
  if (!imu.read(s)) return;
  // The beam pivots about the IMU's Z axis; -s.gz is its rate (negated to match
  // the sign of the accel-derived angle, verified during bring-up). Flip if the
  // gyro fights the accelerometer instead of complementing it.
  balancer.setGains(gains);
  const float angle = Imu::accelAngleDeg(s) - config::kAngleOffsetDeg;  // zero-trim to level
  const ControlInputs in{angle, -s.gz, setpoint, dt, enabled};
  last = balancer.step(in);

  if (last.active) {
    escs.writeThrottle(last.m1, last.m2);
  } else {
    escs.disarm();
  }
  if (last.tripped) enabled = false;  // tilt failsafe latches DISARMED — re-arm from the web

  // Raw-IMU bring-up stream — compiled in only at debug verbosity
  // (LIBRA_LOG_LEVEL >= 4). Throttled to ~10 Hz at the 200 Hz loop.
#if CORE_DEBUG_LEVEL >= 4
  {
    static uint8_t n = 0;
    if (++n >= 20) {
      n = 0;
      log_d("ax=%+.3f ay=%+.3f az=%+.3f | gx=%+.2f gy=%+.2f gz=%+.2f | acc=%+.1f fused=%+.1f", s.ax, s.ay, s.az, s.gx,
            s.gy, s.gz, angle, last.angle);
      // Confirm the control task's stack budget is comfortable during bring-up.
      log_d("control: core=%d stack_free=%u words", xPortGetCoreID(), uxTaskGetStackHighWaterMark(nullptr));
    }
  }
#endif

  web::publish(last.angle, enabled, last.tripped, /*bench=*/false, gains, setpoint);
}

static void handleCommand(String line) {
  line.trim();
  if (line.length() == 0) return;
  if (line == "?") {
#if LIBRA_BENCH_ENABLED
    if (benchActive) {
      log_i("state: BENCH motors=%s m1=%.3f m2=%.3f sp=%.2f kp=%.4f ki=%.4f kd=%.4f", motorsOn ? "ON" : "off", m1Speed,
            m2Speed, setpoint, gains.kp, gains.ki, gains.kd);
    } else
#endif
    {
      log_i("state: %s%s angle=%.2f sp=%.2f out=%.3f m1=%.2f m2=%.2f kp=%.4f ki=%.4f kd=%.4f",
            enabled ? "ARMED" : "disarmed", last.tripped ? " TRIPPED" : "", last.angle, setpoint, last.output, last.m1,
            last.m2, gains.kp, gains.ki, gains.kd);
    }
  }
#if LIBRA_BENCH_ENABLED
  else if (line.startsWith("set motors_enabled ")) {
    // Master switch for manual bench drive. ON applies the per-motor speeds (which default to
    // 0, so enabling never spins on its own); OFF / x holds both at idle. Both suspend
    // balancing — 'run' hands control back to the balancer.
    String v = line.substring(19);
    v.trim();
    v.toLowerCase();
    if (v == "on" || v == "1" || v == "true") {
      benchActive = true;
      motorsOn = true;
      log_w("motors ENABLED (PROPS OFF!) — m1=%.3f m2=%.3f", m1Speed, m2Speed);
      if (m1Speed > config::kMaxThrottle || m2Speed > config::kMaxThrottle) {
        log_w("  note: above the balancing cap kMaxThrottle=%.3f (calibration level).", config::kMaxThrottle);
      }
    } else if (v == "off" || v == "0" || v == "false") {
      benchActive = true;
      motorsOn = false;
      log_i("motors OFF (idle). 'run' resumes balancing.");
    } else {
      log_w("usage: set motors_enabled on|off");
    }
  } else if (line.startsWith("set motors_speed ")) {
    // Per-motor bench throttle: set motors_speed <m1> <m2>, each 0..1. Stored at once and
    // applied while enabled; full range so you can teach the ESC max/min (1.0 then 0.0) by hand.
    String rest = line.substring(17);
    rest.trim();
    const int gap = rest.indexOf(' ');
    if (gap < 0) {
      log_w("usage: set motors_speed <m1> <m2>  (each 0..1)");
    } else {
      m1Speed = throttle::clamp01(rest.substring(0, gap).toFloat());
      m2Speed = throttle::clamp01(rest.substring(gap + 1).toFloat());
      const float u1 = escs.minUs() + m1Speed * (escs.maxUs() - escs.minUs());
      const float u2 = escs.minUs() + m2Speed * (escs.maxUs() - escs.minUs());
      log_i("motors_speed m1=%.4f (%.2f us) m2=%.4f (%.2f us)%s", m1Speed, u1, m2Speed, u2,
            motorsOn ? "" : " — enable with 'set motors_enabled on'");
    }
  } else if (line == "run") {
    benchActive = false;
    log_i("bench off — balancing");
  } else if (line == "x") {
    // Emergency idle (alias for 'set motors_enabled off'): hold both at min. The hardware ESC
    // switch is the real kill; this just parks the signal until 'run'.
    benchActive = true;
    motorsOn = false;
    log_w("STOP: motors idle. 'run' resumes balancing.");
  }
#endif
  else if (line.startsWith("kp ")) {
    gains.kp = line.substring(3).toFloat();
  } else if (line.startsWith("ki ")) {
    gains.ki = line.substring(3).toFloat();
  } else if (line.startsWith("kd ")) {
    gains.kd = line.substring(3).toFloat();
  } else if (line.startsWith("sp ")) {
    setpoint = line.substring(3).toFloat();
  } else {
#if LIBRA_BENCH_ENABLED
    log_w(
        "commands: kp<v> ki<v> kd<v> sp<v> ? | bench(PROPS OFF): set motors_enabled on|off | set motors_speed <m1> "
        "<m2> | run | x");
#else
    log_w("commands: kp<v> ki<v> kd<v> sp<v> ?");
#endif
  }
}

static void pollSerial() {
  static String line;
  while (Serial.available()) {
    const char c = static_cast<char>(Serial.read());
    if (c == '\n' || c == '\r') {
      handleCommand(line);
      line = "";
    } else {
      line += c;
    }
  }
}

// The fixed-rate control loop, in its own task (see the concurrency note at the top).
static void controlTask(void*) {
  TickType_t next_wake = xTaskGetTickCount();
  uint32_t last_us = micros();
  log_i("control task on core %d (prio %u)", xPortGetCoreID(), uxTaskPriorityGet(nullptr));
  for (;;) {
    // Sleep until the next control period — yields the core to WiFi/idle housekeeping
    // instead of busy-spinning. This yield is load-bearing: dropping it starves the
    // FreeRTOS idle task (the C3's shared core, or the WROOM's dedicated core-1 idle),
    // tripping the task watchdog. On an overrun xTaskDelayUntil returns pdFALSE without
    // sleeping, so yield explicitly to keep idle fed.
    if (xTaskDelayUntil(&next_wake, pdMS_TO_TICKS(1000UL / config::kLoopHz)) == pdFALSE) {
      taskYIELD();
    }

    pollSerial();  // polled once per period (200 Hz) — ample for typed commands

    const uint32_t now = micros();
    const float dt = (now - last_us) * 1e-6f;
    last_us = now;
    step(dt);
  }
}

void setup() {
  Serial.begin(115200);
  delay(200);
  Serial.setDebugOutput(true);  // route log_*() output to the USB-CDC serial
  log_i("boot — DISARMED. Arm from the web UI; the ESC supply has its own hardware switch.");

  Wire.begin(config::kI2cSda, config::kI2cScl);
  Wire.setClock(400000);
  // Bound a glitched/contended bus: a stalled read fails fast so step() just skips a
  // cycle instead of hanging the (now higher-priority) control task — which on the
  // WROOM would starve the core-1 idle task and trip its watchdog.
  Wire.setTimeOut(10);  // ms
  if (imu.begin()) {
    log_i("MPU6050 ready");
  } else {
    log_e("MPU6050 not found");
  }

  log_i("ESC arm signal (min throttle held ~3 s)...");
  escs.begin();  // blocks ~3 s arming; must complete before controlTask drives the ESCs
  log_i("ESCs ready (idle). DISARMED — arm from the web UI to balance.");

  web::begin();  // WiFi SoftAP + web UI (setpoint/gains + arm/disarm; WPA2 by default)

  // Hand the loop off to a dedicated, core-pinned task and reclaim loopTask's stack.
  // Created last: the IMU, ESCs, and WiFi are all up before control starts driving.
  xTaskCreatePinnedToCore(controlTask, "control", kControlStackBytes, nullptr, kControlPrio, nullptr, kControlCore);
  vTaskDelete(nullptr);  // setup() runs in loopTask; controlTask now owns the control loop
}

// Never runs after setup() deletes loopTask, but Arduino requires the symbol.
void loop() {}

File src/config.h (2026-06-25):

#pragma once

#include <cstdint>

// Central place for board-specific constants. Pins are for the ESP32-C3 Super
// Mini. VERIFY against your board's silkscreen before wiring. GPIO2 is a
// strapping pin used here for I2C SDA — fine because the bus idles high (the
// level GPIO2 wants at reset), but keep the other strapping pins (GPIO8/GPIO9)
// and the native-USB pins (GPIO18/GPIO19) free.
namespace config {

// --- I2C (MPU6050) ---
#ifndef LIBRA_I2C_SDA
#define LIBRA_I2C_SDA 2
#endif
#ifndef LIBRA_I2C_SCL
#define LIBRA_I2C_SCL 3
#endif
constexpr int kI2cSda = LIBRA_I2C_SDA;
constexpr int kI2cScl = LIBRA_I2C_SCL;
constexpr uint8_t kMpuAddress = 0x68;  // AD0 low

// --- ESC signal pins ---
#ifndef LIBRA_ESC_PIN1
#define LIBRA_ESC_PIN1 0
#endif
#ifndef LIBRA_ESC_PIN2
#define LIBRA_ESC_PIN2 1
#endif
constexpr int kEsc1Pin = LIBRA_ESC_PIN1;
constexpr int kEsc2Pin = LIBRA_ESC_PIN2;

// --- Tilt geometry ---
// The beam pivots about the IMU's Z axis: at rest gravity rests on +X, and
// rotating about Z swings it into Y, so gravity in the X/Y plane gives the tilt
// and the Z gyro axis (negated) gives its rate. Flip this if bring-up shows the
// angle responding to the wrong tilt or with the wrong sign (mounting-dependent).
// (Used by main.cpp when it maps an ImuSample to (accel_angle, rate).)
//
// Zero-offset (deg) subtracted from the measured tilt so a physically level beam
// reads 0. Mounting-specific — measure the resting angle and set it in .env.
// Defaults to 0 (no trim).
#ifndef LIBRA_ANGLE_OFFSET_DEG
#define LIBRA_ANGLE_OFFSET_DEG 0.0f
#endif
constexpr float kAngleOffsetDeg = LIBRA_ANGLE_OFFSET_DEG;

// --- Complementary filter ---
// Gyro weight; the remaining (1 - alpha) trusts the accelerometer.
constexpr float kFilterAlpha = 0.98f;

// --- Control loop ---
constexpr uint32_t kLoopHz = 200;
// The control task paces itself with xTaskDelayUntil at the FreeRTOS tick (1 ms on
// arduino-esp32, configTICK_RATE_HZ == 1000, on both archs). The period is
// pdMS_TO_TICKS(1000 / kLoopHz); if kLoopHz doesn't divide 1000 the rate is silently
// quantized to whole ticks. Keep it an even divisor so 200 Hz stays exactly 200 Hz.
static_assert(1000UL % kLoopHz == 0, "kLoopHz must evenly divide 1000 (1 ms FreeRTOS tick)");

// --- PID (starting gains — tune live over serial) ---
constexpr float kKp = 0.002f;  // throttle fraction per degree of error (full correction ~2.5 deg)
constexpr float kKi = 0.000f;
constexpr float kKd = 0.0008f;

// --- Mixing, throttle band & setpoint (safety) ---
constexpr float kSetpointDeg = 0.0f;  // target tilt: level

// The balancer keeps both propellers inside a throttle band — the single source of motor
// commands (per-motor fraction, 0..1), enforced at the mixer. Three knobs set it:
//   - kMinThrottle (LIBRA_THROTTLE_MIN) — hard floor; a motor never goes below this,
//   - kBaseThrottle (LIBRA_THROTTLE_MID) — hover; where both motors rest at zero error,
//   - kMaxThrottle (LIBRA_THROTTLE_MAX) — hard ceiling; a motor never goes beyond this.
// The PID authority is DERIVED so a full correction can reach the farther band edge from the
// hover point; the mixer clamp holds the nearer edge. So the reachable per-motor range is the
// whole [kMinThrottle, kMaxThrottle] and nothing outside it, regardless of gains.
//
// Set from .env via LIBRA_THROTTLE_MIN / MID / MAX (mise injects them; see platformio.ini).
// Defaults to a ZERO band [0.0, 0.0] with hover 0 -> authority 0: a fresh build never drives
// the motors until you set a real band for your motor. Safe-by-default — the firmware ships
// inert. Fractions map onto the ESC's ~1000-2000 us range (0.0 -> 1000 us idle, 1.0 -> 2000 us
// full); the reference 1404 4600KV/3S rig balances around hover ~0.085 in [0.080, 0.090]
// (~1080-1090 us). Widening the band raises both thrust and control authority — a change the
// safety rules guard (see CLAUDE.md). Props off / beam clamped while you tune.
#ifndef LIBRA_THROTTLE_MIN
#define LIBRA_THROTTLE_MIN 0.0f
#endif
#ifndef LIBRA_THROTTLE_MID
#define LIBRA_THROTTLE_MID 0.0f
#endif
#ifndef LIBRA_THROTTLE_MAX
#define LIBRA_THROTTLE_MAX 0.0f
#endif
constexpr float kMinThrottle = LIBRA_THROTTLE_MIN;
constexpr float kMaxThrottle = LIBRA_THROTTLE_MAX;
constexpr float kBaseThrottle = LIBRA_THROTTLE_MID;  // hover point — set independently within the band
static_assert(kMinThrottle >= 0.0f, "LIBRA_THROTTLE_MIN must be >= 0");
static_assert(kMaxThrottle <= 1.0f, "LIBRA_THROTTLE_MAX must be <= 1 (full throttle)");
static_assert(kMinThrottle <= kMaxThrottle, "LIBRA_THROTTLE_MIN must not exceed LIBRA_THROTTLE_MAX");
static_assert(kBaseThrottle >= kMinThrottle && kBaseThrottle <= kMaxThrottle,
              "LIBRA_THROTTLE_MID (hover) must lie within [LIBRA_THROTTLE_MIN, LIBRA_THROTTLE_MAX]");
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

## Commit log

2026-06-20 chore: project tooling and build config
    PlatformIO + mise for the ESP32-CAM, with a host-only native env for unit
    tests. Fixes the copied-in scaffold (broken extends/default_envs, stale
    per-board tasks) and wires hexdump (asset embedding) into build.
2026-06-20 feat: pure control logic (pid, filter, mixer) with host tests
    Arduino-free, host-testable building blocks: a complementary filter for tilt
    estimation, a PID controller (derivative-on-measurement, output clamp,
    anti-windup), and the differential-thrust mixer. Covered by native Unity tests.
2026-06-20 feat: MPU6050 and ESC hardware drivers
    Imu reads raw accel/gyro over I2C with startup gyro-bias calibration; EscPair
    drives two 1000-2000us servo-PWM ESCs via ESP32Servo with an arming sequence.
    EscPair claims only LEDC timers 2 & 3, leaving timer 0 for the camera XCLK.
2026-06-20 feat: firmware app — control loop, camera, and web UI
    Core-1 control task (IMU -> filter -> PID -> mixer -> ESCs at 200 Hz) with tilt
    failsafe and master enable; core-0 WiFi AP plus two esp_http_server instances
    serving the camera MJPEG stream, telemetry JSON, and live gain tuning. The web
    page renders an FPV view with a telemetry OSD overlay and PID sliders. Cross-core
    state is spinlock-guarded in control_state.
    [config.h, main.cpp]
2026-06-20 docs: project README and contributor guide
    README covers the hardware, wiring/pins, flashing over FTDI, and the web UI.
    CLAUDE.md documents the toolchain, host/hardware split, and the LEDC timer
    constraint between the camera and the ESCs.
2026-06-20 refactor: extract host-tested Balancer for the control policy
    Composes the filter, PID, and mixer into one balancing policy and returns a
    ControlOutputs value. The failsafe-trip, idle-when-disabled, and
    integrator-reset-on-rearm logic now lives here (pure C++) instead of inline in
    the control task — and is covered by native tests for those safety behaviours.
    [test_balancer.cpp]
2026-06-20 refactor: route control loop through Balancer + harden web I/O
    Control task now reads the IMU, calls balancer.step(), and drives the ESCs from
    its ControlOutputs — the balancing policy no longer lives inline in main.
    control_state publishes the ControlOutputs value (no positional float clump) and
    exposes typed setKp/setKi/setKd instead of a stringly-typed setGain(char).
    telemetryHandler guards against an oversized snprintf length before sending,
    closing a latent out-of-bounds read.
    [main.cpp]
2026-06-20 style: leading underscore for private data members
    Switch the convention from trailing (member_) to leading (_member) across all
    the control classes (filter, pid, mixer, imu, esc, balancer). Mechanical rename;
    no behaviour change — tests and build are unaffected.
2026-06-20 docs: tighten CLAUDE.md and drop empty CONTEXT.md
    Promote safety to a top-level guardrail (props/motors are a physical-harm
    risk), make verification an explicit gate, fix stale default env
    (esp32-c3-super-mini -> esp32cam), add a leading-underscore convention
    note and a Gotchas section, and trim architecture narrative now covered
    by README. Remove the empty CONTEXT.md placeholder.
2026-06-20 feat: cap per-motor throttle via LIBRA_MAX_THROTTLE (.env), default 5%
    Enforce a hard ceiling on propeller output at the mixer (the single source
    of motor commands). The cap comes from the LIBRA_MAX_THROTTLE env var, which
    mise injects from .env into the esp32cam build flags; it defaults to 0.05
    (5%) when unset (src/config.h #ifndef + .env.example).
    Scale the operating envelope under the ceiling so the cap never starves
    control authority: base 0.03 +/- differential 0.02 keeps each motor in
    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
2026-06-20 feat: AP SSID/password from .env; rename throttle cap to LIBRA_THROTTLE_MAX
    Move the WiFi AP credentials to the same .env -> mise -> build-flag path as
    the throttle cap: LIBRA_AP_SSID / LIBRA_AP_PASSWORD, quote-wrapped in
    platformio.ini so they reach the compiler as string literals, with the
    prior values ("libra" / "balancebot") as src/config.h defaults.
    Also rename the throttle ceiling var LIBRA_MAX_THROTTLE -> LIBRA_THROTTLE_MAX
    for a consistent LIBRA_THROTTLE_* prefix.
2026-06-20 docs: document the .env -> build-flag config standard
    Add a Configuration section to README (variable table + edit/rebuild flow)
    and a Build-time config convention to CLAUDE.md (naming, quote-wrapping for
    strings, the #ifndef default pattern). Also fix two stale ESP32-C3
    references in the Toolchain block.
2026-06-20 docs: sync stale doc claims with code
    docu-optimizer sync pass found drift between the docs and the code:
    - mise.toml: build comment still named the ESP32-C3 + native USB-CDC;
    correct it to the AI-Thinker ESP32-CAM flashed over USB-TTL/FTDI.
    - main.cpp: document the 'x' emergency-stop serial alias (accepted but
    absent from the command list + usage string).
    - README: the test task also covers the balancer suite; drop the stale
    "(this commit)" marker from the M0 milestone.
    [main.cpp]
2026-06-20 feat: sharpen camera stream (jpeg quality 12->10, +contrast)
    Lower the JPEG quantization on the PSRAM (VGA) path for crisper frames and
    nudge contrast up one step (the OV2640 has no sharpness control). Note in
    the code that a soft image is most often the lens being out of focus.
2026-06-20 feat: capture at XGA + log PSRAM path to fix fullscreen blur
    The web UI shows the stream fullscreen, so a VGA (or QVGA-fallback) frame is
    upscaled by the browser and looks soft regardless of lens focus or sensor.
    Capture at XGA (1024x768) on the PSRAM path so there are enough real pixels
    to fill the display, and log whether PSRAM was detected so a silent QVGA
    fallback (the worst case) is obvious in the boot log.
2026-06-20 refactor: drop camera/WiFi/web — single-core ESP32-C3, serial-only
    Pivot back to the ESP32-C3 Super Mini and strip the FPV/web stack:
    - Board: esp32cam -> esp32-c3-devkitm-1 (env esp32-c3-super-mini); native
    USB-CDC for serial (ARDUINO_USB_MODE / CDC_ON_BOOT), no FTDI/PSRAM/assets.
    - Delete src/camera.*, src/web.*, src/control_state.*, and assets/. The C3 is
    single-core, so the dual-core split + spinlock-guarded shared state are gone:
    main.cpp is now one fixed-rate loop() that polls serial then steps control.
    - Tuning + telemetry move to the serial console (e/d/x/kp/ki/kd/sp/?).
    - config.h: C3 pin map (SDA=5, SCL=6, ESC 3/4), drop AP creds + control core.
    - EscPair: no camera conten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
    [config.h, main.cpp]
2026-06-21 feat: env-configurable pins + tilt limit; move I2C to 2/3, ESCs to 0/1
    Reassign the pin map (SDA=GPIO2, SCL=GPIO3, ESC1=GPIO0, ESC2=GPIO1) and make
    the pins and the tilt failsafe angle .env-tunable via build flags, same
    pattern as LIBRA_THROTTLE_MAX:
    LIBRA_I2C_SDA / LIBRA_I2C_SCL (default 2 / 3)
    LIBRA_ESC_PIN1 / LIBRA_ESC_PIN2 (default 0 / 1)
    LIBRA_TILT_LIMIT_DEG (default 45.0)
    Each has an #ifndef default in config.h so a flag-less build still works.
    GPIO2 (SDA) is a strapping pin — fine since I2C idles high; noted in config.h
    and README. Docs (.env.example, README config table + pins note) updated.
    [config.h]
2026-06-21 feat: env-configurable WiFi AP credentials
    Add LIBRA_AP_SSID / LIBRA_AP_PASSWORD knobs (defaults libra / balancebot)
    following the existing env→build-flag→config.h convention, for the
    upcoming tuning web UI. WPA2 needs an 8-63 char password.
2026-06-21 feat: web module — WiFi SoftAP + httpd tuning UI
    New Arduino-only src/web: a WPA2 SoftAP and an ESP-IDF httpd server on
    :80 serving a one-page UI (/, /telemetry, /set) with sliders for the
    setpoint and PID gains. httpd handlers run in their own task, so the
    small command/telemetry state is spinlock-guarded and exchanged with the
    control loop via web::poll() / web::publish().
    Safety by construction: /set carries setpoint + gains only (no arm), and
    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
2026-06-21 docs: document the web tuning UI
    README: serial+web framing, web path in Diagram 1, a Web control section,
    Configuration rows, and a tuning note. CLAUDE.md: safety bullet (web sets
    setpoint/gains only, never arm), src/web layout entry, and a replaced
    gotcha for the WiFi web UI.
2026-06-21 fix(imu): correct pivot axis to Z; add env-var debug logging
    Hardware bring-up showed the IMU rests with gravity on +X and pivots
    about Z, not X. accelAngleDeg now uses atan2(ay, ax) and the control
    loop uses -s.gz as the rate (was atan2(ay, az) / s.gx). Level now reads
    ~0deg instead of ~135deg, so the tilt failsafe no longer trips at rest.
    Verified on serial: steady at level, tracks +/-tilt smoothly, and the
    fused angle stays within ~1deg of the accel angle in motion (gyro
    complements rather than fights).
    Debug logging via the ESP32 API: LIBRA_LOG_LEVEL (.env) -> CORE_DEBUG_LEVEL.
    At >=4 (debug) it compiles in a ~10 Hz raw-IMU serial stream (log_d) used
    for this bring-up, plus the AP passw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
    [config.h, main.cpp]
2026-06-21 feat: env-configurable IMU tilt zero-offset (LIBRA_ANGLE_OFFSET_DEG)
    Subtract a configurable zero-offset from the measured tilt so a
    physically level beam reads 0deg. Default 0.0 (no trim); set in .env
    after measuring the resting angle with LIBRA_LOG_LEVEL=4. On this rig
    -3.4 zeroes it (verified: level now reads ~0.2deg, was -3.4deg).
    Follows the established .env -> build-flag -> config.h #ifndef ->
    constexpr convention; applied in main.cpp's ImuSample -> ControlInputs
    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
2026-06-21 docs: document the test/debug strategy + add serial-debug tooling
    Capture the bring-up workflow this hardware needs so it is repeatable:
    - tools/serial_dbg.py: non-interactive serial helper (probe/banner/stream).
    The firmware only prints on boot + on command and native USB-CDC does not
    reset on monitor attach, so an interactive monitor looks dead. These talk
    to the board headlessly and reset it cleanly (RTS pulse into the app).
    - mise tasks: probe / banner / stream wrap it for one-command use.
    - docs/testing.md: full guide — host tests (the fast loop), build/flash,
    the monitor-looks-dead gotcha, LIBRA_LOG_LEVEL debug stream, IMU axis +
    zero-offset bring-up, WSL2 serial/port-busy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
    [serial_dbg.py]
2026-06-21 fix(loop): yield the core to WiFi via vTaskDelayUntil
    The single-core C3 ran loop() as a tight busy-wait between 5 ms control steps,
    starving the FreeRTOS idle task and WiFi/lwIP housekeeping. Sleep to the next
    period instead so the radio gets the core; dt stays measured from micros().
    [main.cpp]
2026-06-21 feat(web): open AP, /set lock-scope fix, client join/leave logging
    - Parse /set query args before taking the spinlock — no string/float parsing
    with interrupts disabled on the WiFi core.
    - SoftAP is now open (no WPA2); arming stays serial-only so no thrust is exposed,
    and it avoids WPA2 association failures. Drops the unused kApPassword.
    - Log AP client join/leave events unconditionally, for connection debugging.
    [config.h]
2026-06-21 build: per-board pin map + ESP32 WROOM-32 env
    Pins are board hardware, so they live as literal -D flags per [env] (not .env).
    Shared tunables move to a [tunables] section interpolated into each board via
    ${tunables.build_flags}; .env still overrides them. Adds the esp32-wroom32 env
    (USB-UART bridge, I2C SDA=32/SCL=33, ESC 25/26 — all non-strapping pins).
2026-06-21 refactor: drop unused kLoopPeriodUs
    The loop computes its period from kLoopHz via pdMS_TO_TICKS(); kLoopPeriodUs is
    no longer referenced after the vTaskDelayUntil change.
    [config.h]
2026-06-21 docs(readme): open AP, per-board pins, WROOM-32 board
    Sync the README with this session's changes: SoftAP is open (drop the WPA2
    password references), the pin map moved from .env to per-board -D flags in
    platformio.ini (drop the I2C/ESC .env rows), and a second board (ESP32 WROOM-32,
    dual-core) is now supported alongside the C3.
2026-06-21 docs(claude): fix loop/build-config/board drift
    - Conventions: loop now sleeps via vTaskDelayUntil (was 'never delay a step').
    - Build-time config: document the two-tier split (per-board literal pins vs .env
    tunables in the [tunables] section).
    - Layout: config.h holds AP SSID only (open AP), pin defaults are a fallback.
    - Note the WROOM-32 board (default env, USB-UART bridge) alongside the C3.
2026-06-21 feat(control): run the control loop in a dedicated core-pinned task
    Move the fixed-rate loop out of loop() into a controlTask pinned to
    ARDUINO_RUNNING_CORE: the APP core (1) on the dual-core WROOM-32 — isolated from
    WiFi/lwIP/httpd on the PRO core (0) — and the only core on the single-core C3,
    where priority 10 (above httpd, below lwIP/WiFi) plus a per-period xTaskDelayUntil
    yield keep WiFi fed. setup() spawns it and deletes loopTask.
    - config.h: static_assert that kLoopHz evenly divides the 1 ms FreeRTOS tick.
    - web.cpp: pin httpd to core 0 on both archs; WiFi.setSleep(false) (no-op in AP).
    - Wire.setTimeOut(10) bounds the blocking IMU read so a glitched bus skips a step.
    Co-Authored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
    [config.h, main.cpp]
2026-06-21 build: add build:all dual-arch compile gate
    Compiles both esp32-wroom32 and esp32-c3-super-mini; the control task's core
    selection differs per arch, so build both before declaring a change done.
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2026-06-21 feat(control): replace software arming with a hardware ESC switch
    The control loop now always runs; arming is a physical switch on the ESC
    supply, not a software master-enable. Removes the `enabled` flag, the serial
    e/d/x arm/disarm commands, disarmed-on-boot, and the trip re-arm latch.
    The tilt failsafe is unchanged and becomes the sole software safeguard:
    balancer.step() still idles the motors past kTiltLimitDeg and now auto-resumes
    (with a fresh PID integrator, via the existing inactive->active reset) once the
    beam is back within the limit — no Balancer change needed.
    Drops `enabled` from the web telemetry/publish path and the UI status (now
    tripped/balancing). Updates the CLAUDE.md s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
    [main.cpp]
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2026-06-21 feat(web): add optional WPA2 password for the tuning AP
    New LIBRA_AP_PASS tunable (default empty = open AP, unchanged behavior). When
    set to >= 8 chars, the SoftAP comes up WPA2-protected; a shorter non-empty value
    is rejected at boot and falls back to open. The boot log states which mode.
    The web UI still cannot arm (arming is the hardware ESC switch), so the open
    default stays safe — the password just keeps stray clients off the tuning UI.
    Follows the .env tunable pattern: documented in .env.example, wired through
    [tunables] in platformio.ini, with an #ifndef default in config.h.
    [config.h]
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2026-06-21 refactor(esc): explicit per-motor bench interface (drop auto-MAX cal)
    The previous `cal` command jumped both ESCs to full throttle the instant it was
    typed — too easy to fire by accident. Replace it (and the `t <v>`/`!` command)
    with an explicit, per-motor manual-drive interface where nothing moves on its own:
    set motors_enabled on|off master switch; motors hold the set speeds, else idle
    set motors_speed <m1> <m2> per-motor throttle, each 0..1 (default 0)
    run resume autonomous balancing
    x force motors idle
    Speeds default to 0, so enabling never spins; you raise to 1.0 then 0.0 by hand
    to teach the ESC throttle range, and can dr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
    [main.cpp]
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2026-06-21 feat: gate bench/calibration commands behind LIBRA_BENCH_ENABLED
    The props-off bench commands (set motors_enabled / set motors_speed / run / x)
    drive the ESCs directly, bypassing the kMaxThrottle cap and the tilt failsafe.
    Compile them out by default and gate them behind a new LIBRA_BENCH_ENABLED knob:
    - 0 (default): the bench code is #if'd out — a props-on build has no safeguard
    bypass and no way to enter manual drive; serial offers only kp/ki/kd/sp/?.
    - 1: bench commands available for ESC calibration / spin-start work.
    Wired through .env (LIBRA_BENCH_ENABLED) + [tunables] in platformio.ini, with an
    #ifndef default of 0 in config.h. Both paths verified to build on both archs.
    Co-Auth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
    [config.h, main.cpp]
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2026-06-21 docs: document the bench/calibration workflow + reference hardware
    Make the bench setup official:
    - README: reference build (1404 4600KV, Afro Mini, Gemfan 3523-3 props, 3S LiPo,
    hardware arm switch); note the 200 Hz sub-us LEDC drive; fix the stale WROOM ESC
    pins (now GPIO16 left/m1, GPIO17 right/m2).
    - docs/testing.md §7: rebuilt around `mise run sweep` / tools/sweep.py and the
    LIBRA_BENCH_ENABLED gate — find the usable band (--motor 1|2|seq to isolate a
    dead channel), set the operating band (kBaseThrottle/kPidOutLimit/LIBRA_THROTTLE_MAX),
    and the optional throttle-range calibration. §3 notes the bench commands need the flag.
    - CLAUDE.md: note the LIBRA_BENCH_ENABLED gate in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
2026-06-21 feat(web): add web arm/disarm (software master-enable, boots disarmed)
    Re-introduce a software master-enable controlled from the web UI, layered with the
    hardware ESC-power switch: the board boots DISARMED, ARM/DISARM buttons on the web
    page toggle `enabled`, and the firmware idles the ESCs until armed. The hardware
    switch still gates ESC energy; the tilt failsafe cuts the motors and latches
    disarmed (re-arm from the web).
    - web: ARM/DISARM buttons + `enabled` telemetry; /set?en=0|1 stages the request;
    pollArm() hands it to the control loop, which owns `enabled`.
    - main: apply the web arm request, pass `enabled` to the balancer, latch disarmed on
    a tilt trip; `?` shows ARMED/disarmed.
    -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
    [config.h, main.cpp]
2026-06-21 tune(control): set the throttle band to the motor's 1080-1090 us window
    The balancer's defaults (base ~1030 / cap ~1050 us) sat below the reference motor's
    ~1080 us spin-start, so an armed beam never actually drove the motors. Move the band
    onto the motor:
    - kBaseThrottle 0.03 -> 0.085 (1085 us, just above spin-start)
    - kPidOutLimit 0.02 -> 0.005 (+/-5 us; both motors stay within 1080-1090)
    - kKp 0.010 -> 0.002 (full correction at ~2.5 deg; tune live)
    - LIBRA_THROTTLE_MAX default 0.05 -> 0.090 (config.h + .env.example) so base+limit
    stays <= the cap
    Flashed + verified: boots disarmed, kp=0.0020. Re-find this band for a different
    motor (docs/testing.md section 7).
    Co-Authored-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
    [config.h]
2026-06-22 feat(tools): add 'mise run hexdump' to embed assets as PROGMEM headers
    xxd -i each file under assets/ into assets/<file>.h as a const PROGMEM byte
    array + length, so assets ship in flash with no on-device filesystem. The
    generated *.h are skipped, so re-runs are idempotent.
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2026-06-22 add 3dprint files
    [arm.3mf, arm.f3d, arm.stl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]
2026-06-22 docs: fix env/status drift, add the dual-arch compile gate, dedup arming note
    - README: build comment said ESP32-C3 but the default env is esp32-wroom32;
    extend the Status milestones past M3 (M4 web UI + arming, M5 bench tooling).
    - CLAUDE.md + testing.md: add `mise run build:all` to the before-done gate so
    both docs name the same gate (test + format-check + build:all).
    - CLAUDE.md: trim the web-UI gotcha's restatement of the arming model to a
    pointer to the canonical Safety section (it's stated there already).
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2026-06-22 refactor: derive the balancing throttle band from [MIN, MAX]
    Replace the lone kMaxThrottle ceiling with an explicit per-motor band
    [kMinThrottle, kMaxThrottle], adding LIBRA_THROTTLE_MIN alongside the
    existing LIBRA_THROTTLE_MAX tunable. The hover throttle (kBaseThrottle)
    and the PID authority (kPidOutLimit) are now DERIVED from the band — the
    midpoint and half-width respectively — so base ± kPidOutLimit spans
    exactly [MIN, MAX]: a full correction drives one motor to MAX as the
    other drops to MIN.
    Behavior-preserving: the defaults [0.080, 0.090] reproduce the previous
    hover 0.085 / authority ±0.005 on the reference rig. The mixer's lower
    clamp moves from a hardcoded 0.0 to kMinThrottl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
    [config.h, main.cpp]
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2026-06-22 feat: add LIBRA_THROTTLE_MID for an independent hover point
    Decouple the hover throttle from the band geometry. Previously
    kBaseThrottle was forced to the band midpoint, so MIN=0/MAX=1 had to
    hover at 50%. Add a third tunable, LIBRA_THROTTLE_MID, that sets the
    resting throttle anywhere within [MIN, MAX]:
    MIN hard floor — a motor never goes below it
    MID hover point — where both motors rest at zero error
    MAX hard ceiling — a motor never goes beyond it
    kPidOutLimit is now derived as the max headroom from the hover point,
    max(MAX - MID, MID - MIN), so a full correction can still reach the
    farther edge while the mixer clamp holds the nearer one. A static_assert
    requires MIN <=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
    [config.h]
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2026-06-25 docs: sync AP-password docs/comments with the WPA2 default
    The README, .env-adjacent comments, and code comments still described the
    AP as open-by-default and (in main.cpp) claimed arming was serial-only.
    Update them: add the LIBRA_AP_PASS row to the README tunables table,
    reword the join/web-control sections, and fix the stale begin() and
    web::begin() comments to match the current arm-from-web model.
    [main.cpp]
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
